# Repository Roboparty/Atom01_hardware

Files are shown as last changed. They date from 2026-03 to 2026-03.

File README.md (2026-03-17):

# ATOM01_HARDWARE - RoboParty Humanoid Robot Open Source Project

**[中文](./README_cn.md)** | English

> **Project Introduction:** This repository serves as the core open-source hardware library for the **ATOM01** series of humanoid robots. We are committed to lowering the barrier to entry for bipedal robot development by providing a complete solution encompassing mechanical design, PCB schematics, and firmware.

---

## 📂 Repository Overview (Structure)

The project is managed hierarchically based on **version iterations**, containing two primary development branches: **V1.0** and **V2.0**.

### 📊 V1.0 vs V2.0 Feature Comparison

| Feature | V1.0 (Legacy) | V2.0 (Current / Recommended) |
| :--- | :--- | :--- |
| **Mechanical Design** | Original Design | **Reinforced Structure** |
| **Hardware Architecture** | Discrete Modules | **Highly Integrated Single Board** |
| **Core Improvements** | - | **Waist Limiting, Pin Calibration, Backplate Switch** |
| **Use Case** | Legacy User Maintenance | New User Development, Mass Production |

---

### 🔧 V1.0 (atom01_mechanic / atom01_pcb)
**Positioning:** Original version containing the early mechanical structure and discrete circuit board design.

-   **Core Components:**
    -   **Mechanical:** Basic bipedal structure design, including early assembly documentation and URDF files.
    -   **Hardware:** Separate Power and Communication boards (Roboto_Power, Roboto_Usb2Can).
-   **Target Audience:** Limited to legacy users still utilizing the first-generation hardware for reference.

### 🚀 V2.0 (roboto_origin_mechanic / roboto_origin_pcb)
**Positioning:** Brand new optimized version, comprehensively restructured for usability, stability, and integration.

#### ✨ Core Update Highlights
-   **🚀 Hardware System: Single Board Integration**
    -   **Optimization:** Integrated modules such as power management and communication interfaces into a **single core circuit board**.
    -   **Advantage:** Significantly simplifies internal cabling, reduces connector failure points, and enhances system stability and EMC (Electromagnetic Compatibility).
-   **⚙️ Mechanical System: Structural Reinforcement & Calibration Upgrade**
    -   **Waist Limiting:** Added a **mechanical limit switch** to ensure absolute safety for waist rotation angles.
    -   **Calibration Method:** Introduced **limit pin calibration** process, replacing the generic calibration method of the old version.
    -   **Arm Optimization:** Corrected issues present in the arm components of the previous version.
    -   **Backplate Switch:** Added a physical **main control board switch** to the robot's backplate.
-   **Target Audience:** All new users, developers, and users looking to experience the latest features.

---

## 📚 Quick Start

Please enter the corresponding directory based on your hardware version to obtain detailed documentation:

.  **V2.0 Users (Recommended):**
    -   **Mechanical Drawings:** Enter `V2.0/roboto_origin_mechanic/` to view assembly drawings and STL files.
    -   **PCB Files:** Enter `V2.0/roboto_origin_pcb/` to obtain Gerber files and schematics.
.  **V1.0 Users:**
    -   **Mechanical Drawings:** Enter `V1.0/atom01_mechanic/`.
    -   **PCB Files:** Enter `V1.0/atom01_pcb/`.

---

> **Note:** The mechanical structure and hardware interfaces of **V2.0 are not compatible with V1.0**. Please confirm the version before assembly or purchasing materials.

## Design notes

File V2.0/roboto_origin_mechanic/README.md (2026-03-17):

# ROBOTO

**[中文](./README_cn.md)** | English

> **Project Introduction:** This project is an open-source bipedal robot. It aims to lower the assembly threshold by providing a "nanny-level" assembly tutorial from mechanical structure to circuit connection.

---

## 📚 Core Documentation Navigation

We have prepared detailed PDF manuals for beginners. **Please be sure to read them in the following order:**

| Order | Document Name | Description | Location |
| :---: | :--- | :--- | :--- |
| 1️⃣ | **[Installation Manual-0317.pdf](00_Docs/安装手册-0317.pdf)** | Core assembly tutorial | `00_Docs/` |
| 2️⃣ | **[Roboto_origin Wiring Guide.pdf](00_Docs/Roboto_origin走线说明.pdf)** | Electronic wiring guide | `00_Docs/` |
| 3️⃣ | **[Pin Calibration Guide.pdf](00_Docs/插销标定说明.pdf)** | Pin calibration method | `00_Docs/` |
| 4️⃣ | **[3D Printed Parts Calibration Guide.pptx](00_Docs/3D打印件标定说明.pptx)** | 3D printing calibration guide | `00_Docs/` |

---

## 📂 Project File Structure

This repository uses a modular structure, organized as follows:

```text
├── 00_Docs/                         # [Docs] Core manuals and lists
│   ├── 3D打印件标定说明.pptx        # 3D Printing Calibration Guide
│   ├── 安装手册-0317.pdf             # Installation Manual
│   ├── 插销标定说明.pdf              # Pin Calibration Guide
│   ├── Roboto头原型机 (RoboParty Roboto Origin) 散件清单 V1.1.3.xlsx # Parts List
│   ├── Original-0310.pdf             # Original Document
│   ├── Roboto_origin走线说明.pdf     # Wiring Guide
│
├── 01_SW_Project/                   # [Source] SolidWorks engineering files
│   └── robo_origin_2.0               # Roboto Origin 2.0 SW Project
│
├── 02_Manufacturing/                # [Manufacturing] Production files
│   ├── 3D_Printing                  # 3D Printing related files
│   └── CNC_Machining                # CNC Machining related files
│
└── 03_URDF/                         # [Simulation] Robot Description Files
    ├── meshes                       # Simulation model mesh files
    ├── urdf                         # URDF configuration files
    ├── Readme.md                    # URDF folder Readme
    └── robo_origin.png              # Image file

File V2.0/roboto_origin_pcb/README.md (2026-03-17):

# RBE_Board V2.0 - Robotic Electrical Hub

**[中文](./README_cn.md)** | English





> **Project Introduction:** The **RBE_Board V2.0** is an integrated circuit board designed by **RoboParty** for high-performance bipedal robots. It integrates three key functions: **48V-to-5V step-down conversion**, **power distribution**, and **USB-to-CAN communication**. This board acts as the "electrical hub" of the robot, responsible for power allocation and communication signal distribution.

---

## 📖 Specifications

As the key connection between the battery, the main control board (e.g., Orange Pi 5 Plus), and the limb actuators, the core specifications are as follows:

### 1. Hardware Specifications Table

| Parameter Category | Specification | Notes |
| :--- | :--- | :--- |
| **Power Input** | XT60 Terminal, 48VDC | Connect to Battery PACK |
| **5V Output** | Type-C Interface, Max 8A | Power supply for Main Control Board (e.g., Orange Pi 5 Plus) |
| **48V Output** | XT30 (2+2) Terminals × 4 | Distributed to limb motors |
| **Communication Interface** | USB 2.0 (Type-C) | Connects to Main Control Board for USB-to-CAN function |
| **Cooling Supply** | GH1.25 Interface, 5V | Powers system fans |
| **Dimensions** | 80mm × 60mm | Compact design |

---

## 📂 Repository Structure

This repository contains all engineering files required for manufacturing and utilizing this module:

```text
├── 00_Docs/                         # Documentation
│   ├── Images/                      # Interface & Render Images
│   │   ├── RBE_Board_v2.0_interface_bottom.PNG  # Bottom Interface Definition
│   │   ├── RBE_Board_v2.0_interface_top.PNG     # Top Interface Definition
│   │   └── RBE_Board_v2.0_render.JPEG           # 3D Render Image
│   ├── 3D_PCB5_11_2026-2-1.step    # 3D Structure Model File
│   └── 三合一电路V1.0硬件说明.pdf   # Detailed Hardware Design Principles (Chinese)
│
├── 01_Gerber/                       # PCB Manufacturing Files
│   └── Gerber_RBE_Board_v2.0.zip    # Gerber File Archive
│
├── 02_Assembly/                     # Assembly Files
│   ├── BOM_RBE_Board_v2.0.xlsx      # Bill of Materials (BOM)
│   └── PickAndPlace_RBE_Board_v2.0.xlsx # Pick and Place Coordinates
│
├── README.md                        # English Readme
└── README_cn.md                     # Chinese Readme

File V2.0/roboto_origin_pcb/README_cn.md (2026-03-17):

# RBE_Board V2.0 - 机器人电气核心枢纽

**[中文](./README_cn.md)** | [English](./README.md)

!<Manufacturer>
!<Hardware>
!<OS>

> **项目简介：** RBE_Board V2.0 是萝博派对 (RoboParty) 专为高性能双足机器人设计的集成化电路板。该板卡将 **48V转5V降压模块**、**分电板** 以及 **USB转CAN (USB2CAN)** 功能集成于一体，作为机器人的“电气中转站”，负责电源分配与通信信号分发。

---

## 📖 核心功能与规格 (Specifications)

本模块作为连接电池、主控板（如香橙派5Plus）与四肢执行器的关键枢纽，核心参数如下：

### 1. 硬件参数表

| 参数类别 | 具体规格 | 备注 |
| :--- | :--- | :--- |
| **供电输入** | XT60端子, 48VDC | 连接电池 PACK |
| **5V 输出** | Type-C接口, 最高持续电流 8A | 为主控板、供电 |
| **48V 输出** | XT30 (2+2) 端子 × 4 | 分配至机器人四肢电机 |
| **通信接口** | USB2.0 (Type-C) | 连接主控板，实现 USB 转 CAN 功能 |
| **散热供电** | GH1.25 接口, 5V | 为系统风扇供电 |
| **尺寸** | 80mm × 60mm | 紧凑型设计 |

---

## 📂 仓库目录结构 (File Structure)

本仓库包含制造和使用该模块所需的全部工程文件：

```text
├── 00_Docs/                         # 文档目录
│   ├── Images/                      # 接口与渲染图
│   │   ├── RBE_Board_v2.0_interface_bottom.PNG  # 底部接口定义
│   │   ├── RBE_Board_v2.0_interface_top.PNG     # 顶部接口定义
│   │   └── RBE_Board_v2.0_render.JPEG           # 3D渲染效果图
│   ├── 3D_PCB5_11_2026-2-1.step    # 3D结构模型文件
│   └── 三合一电路V1.0硬件说明.pdf   # 详细硬件设计原理
│
├── 01_Gerber/                       # PCB制造文件
│   └── Gerber_RBE_Board_v2.0.zip    # Gerber文件压缩包
│
├── 02_Assembly/                     # 装配文件
│   ├── BOM_RBE_Board_v2.0.xlsx      # 物料清单
│   └── PickAndPlace_RBE_Board_v2.0.xlsx # 贴片坐标文件

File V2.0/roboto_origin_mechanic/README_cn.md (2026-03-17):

# ROBOTO

**[中文](./README_cn.md)** | [English](./README.md)

> **项目简介：** 本项目是一个开源的双足机器人。本项目致力于降低组装门槛，提供了从机械结构到电路连接的“保姆级”装配教程。

---

## 📚 核心文档导航 (Documentation)

我们为初学者准备了详细的 PDF 手册，请**务必按照以下顺序阅读**：

| 顺序 | 文档名称 | 内容说明 | 存放位置 |
| :---: | :--- | :--- | :--- |
| 1️⃣ | **[安装手册-0317.pdf](00_Docs/安装手册-0317.pdf)** | 核心组装教程 | `00_Docs/` |
| 2️⃣ | **[Roboto_origin走线说明.pdf](00_Docs/Roboto_origin走线说明.pdf)** | 电子接线指导 | `00_Docs/` |
| 3️⃣ | **[插销标定说明.pdf](00_Docs/插销标定说明.pdf)** | 插销标定方法 | `00_Docs/` |
| 4️⃣ | **[3D打印件标定说明.pptx](00_Docs/3D打印件标定说明.pptx)** | 3D打印件标定说明 | `00_Docs/` |

---

## 📂 项目文件架构 (File Structure)

本仓库采用模块化结构，文件组织如下：

```text
├── 00_Docs/                         # [文档] 核心说明书
│   ├── 安装手册-0317.pdf            # 核心安装手册
│   ├── 插销标定说明.pdf             # 插销标定说明
│   ├── Roboto头原型机 (RoboParty Roboto Origin) 散件清单 V1.1.3.xlsx # 散件清单
│   ├── Original-0310.pdf            # 产品介绍书
│   ├── robo_origin SOP.pdf          # 标准作业程序
│   └──Roboto_origin走线说明.pdf      # 走线说明  
│
├── 01_SW_Project/                   # [源文件] solidworks工程文件
│   └── robo_origin_2.0              # Roboto Origin 2.0 工程文件
│
├── 02_Manufacturing/                # [制造] 生产加工文件
│   ├── 3D_Printing                  # 3D打印相关文件
│   └── CNC_Machining                # CNC加工相关文件
│
└── 03_URDF/                         # [仿真] 机器人描述文件
    ├── meshes                       # 仿真模型网格文件
    ├── urdf                         # URDF配置文件

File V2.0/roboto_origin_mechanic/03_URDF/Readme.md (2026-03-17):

This is the URDF file of Atom01, a product of Roboparty.
Atom01 URDF 模型  
  <link
    name="left_ankle_roll_link">
    <inertial>
      <origin
        xyz="0.01521399 0.00220247 -0.02960539"
        rpy="0 0 0" />
      <mass
        value="0.32034036 " />
      <inertia
        ixx=" 0.000402"
        ixy="0"
        ixz="0.00017084"
        iyy="0.00089244"
        iyz="-0.00000894"
        izz="0.0006553" />
    </inertial>

      <link
    name="right_ankle_roll_link">
    <inertial>
      <origin
        xyz="0.01521399 -0.00220269 -0.02960539"
        rpy="0 0 0" />
      <mass
        value="0.32034036" />
      <inertia
        ixx="0.000402"
        ixy="0"
        ixz="-0.00017084"
        iyy="0.00089244"
        iyz="-0.00000894"
        izz="0.0006553" />
    </inertial>

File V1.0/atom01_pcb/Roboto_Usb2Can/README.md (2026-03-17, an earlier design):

# Roboto_Usb2Can_V1.0 - USB to 4-Channel CAN Communication Module

[English](./README.md) | **[🇨🇳 中文](./README_cn.md)**





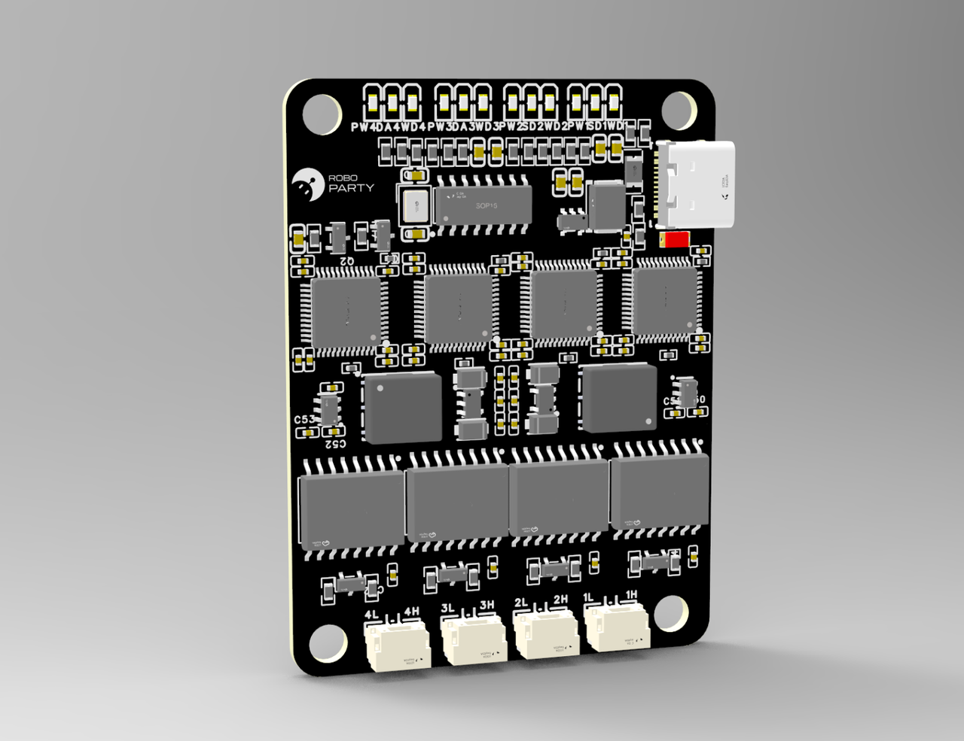
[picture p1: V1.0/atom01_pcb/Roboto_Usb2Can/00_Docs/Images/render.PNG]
Render


## 📖 Overview

**Roboto_Usb2Can_V1.0** is a highly integrated communication conversion device developed by **RoboParty**.

Designed primarily for robot control systems, this module converts USB signals from a host computer (such as an Orange Pi 5 Plus or other Linux devices) into **4 independent CAN bus signals**, enabling efficient control of actuators like servo motors.

> ⚠️ **Note:** This device currently only supports recognition and usage on **Linux systems**.

## 📂 Repository Structure

This repository contains all files required to manufacture and use this module:

- **PCB Manufacturing Files (Gerber):** `01_Gerber/`
- **BOM & Coordinate Files:** `02_Assembly/`
- **Firmware Files:** `03_Firmware/`
- **Detailed Documentation:** `00_Docs/`

## 🔌 Interfaces

### 1. Hardware Interface Layout
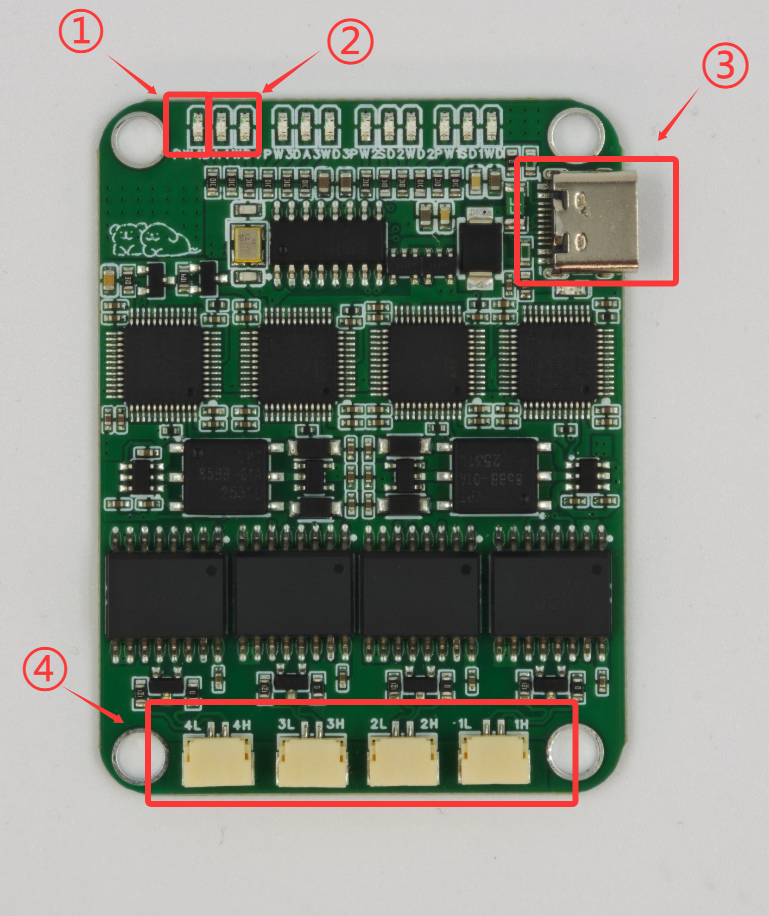
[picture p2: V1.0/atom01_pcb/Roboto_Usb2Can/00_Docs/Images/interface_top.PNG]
Interfaces


| No. | Name | Type | Description |
| :--- | :--- | :--- | :--- |
| **①/④** | **Mounting Holes** | Mechanical | Standard mounting holes |
| **②** | **Flashing LEDs** | LED | Status indicators for the 4 backend channels |
| **③** | **USB-C** | Data/Power | Connects to Host (Linux), 5V Input |
| **④** | **CAN Interfaces** | GH1.25 | 4-channel CAN bus output (4L, 4H, 3L, 3H...) |

### 2. Recommended Connection Topology
For easier management, we recommend connecting the robot joints in the following order:

- **CAN 1:** Left Leg 
- **CAN 2:** Right Leg(including Waist)
- **CAN 3:** Left Arm
- **CAN 4:** Right Arm

## 🛠️ Firmware Flashing Guide

There are 4 sets of SWD programming interfaces reserved on the back of the device. You will need to use **1.25mm programming probes (pogo pins)** with an ST-Link or similar tool.

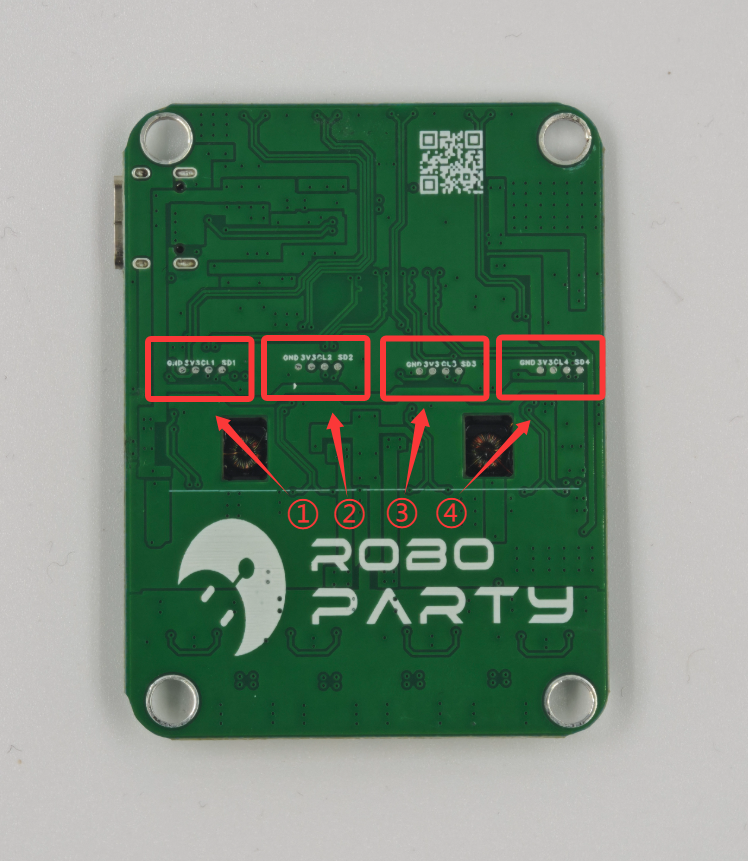
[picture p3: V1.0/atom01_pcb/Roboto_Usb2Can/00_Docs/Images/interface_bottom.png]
Flashing Ports


### Flashing Steps:
1.  **Download Firmware:** Get [RoboParty-HubUsb2Can_1.00.bin](03_Firmware/RoboParty-HubUsb2Can_1.00.bin).
2.  **Connect Programmer:** The pinout from left to right is: `GND`, `3V3`, `CLK`, `DIO`.
3.  **Sequential Flashing:** Please flash the firmware to the **4 programming ports** on the back one by one (each port corresponds to one CAN control chip).

## ⚠️ Precautions

1.  **Power Safety:**
    * **5V Power Supply ONLY.** Do not connect higher voltages.
    * Do not forcibly insert the Type-C cable in reverse.
2.  **Termination Resistors:**
    * The CAN bus specification requires a **120Ω termination resistor** at the end of each bus.
    * If your servo motors have internal resistors, no extra action is needed; otherwise, you must add a parallel resistor at the end of the chain.
3.  **Environmental Requirements:**
    * Avoid contact with water, conductive dust, or metal debris to prevent short circuits.

## 🏭 Manufacturing Downloads

If you need to manufacture this module yourself, please download the following files:

* **Gerber Files (PCB Fab):** [Roboto_Usb2Can_V1.0.rar](01_Gerber/Roboto_Usb2Can_V1.0.rar)
* **Bill of Materials (BOM):** [HUB-USB2CAN_Bom.xlsx](02_Assembly/HUB-USB2CAN_Bom.xlsx)
* **Pick & Place Coordinates (CPL):** [PickAndPlace.xlsx](02_Assembly/PickAndPlace_HUB_USBTOCAN_V1_0.xlsx)

---
**Tech Support:** If you encounter technical issues, please contact the RoboParty technical team.

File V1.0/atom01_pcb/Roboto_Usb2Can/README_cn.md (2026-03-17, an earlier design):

# Roboto_Usb2Can_V1.0 - USB 转 4路 CAN 通讯模块

**[中文](./README_cn.md)** | [English](./README.md)





Render

## 📖 概述 (Overview)

**Roboto_Usb2Can_V1.0** 是由 **萝博派对 (RoboParty)** 研发的高集成度通讯转换设备。

该模块主要用于机器人控制系统，能够将上位机（如 Orange Pi 5 Plus 等 Linux 设备）的 USB 信号转换为 **4 路独立的 CAN 总线信号**，从而实现对伺服电机等执行机构的高效控制。

> ⚠️ **注意：** 本设备目前仅支持在 **Linux 系统** 下识别和使用。

## 📂 仓库目录 (File Structure)

本仓库包含制造和使用该模块所需的所有文件：

- **PCB 制造文件 (Gerber):** `01_Gerber/`
- **BOM 与坐标文件:** `02_Assembly/`
- **固件文件:** `03_Firmware/`
- **详细说明文档:** `00_Docs/`

## 🔌 接口定义 (Interfaces)

### 1. 硬件接口布局
Interfaces

| 编号 | 名称 | 类型 | 说明 |
| :--- | :--- | :--- | :--- |
| **①/④** | **固定孔** | 机械 | 标准安装孔位 |
| **②** | **烧录指示灯** | LED | 对应背部 4 路烧录状态 |
| **③** | **USB-C** | 数据/电源 | 连接上位机 (Linux)，输入电压 5V |
| **④** | **CAN 接口** | GH1.25 | 4路 CAN 总线输出 (4L, 4H, 3L, 3H...) |

### 2. 执行机构连接推荐
为方便管理，建议按照以下对应关系连接机器人关节：

- **CAN 1:** 左腿 
- **CAN 2:** 右腿(含腰关节)
- **CAN 3:** 左臂
- **CAN 4:** 右臂

## 🛠️ 烧录指南 (Firmware Flashing)

本设备背面预留了 4 组 SWD 烧录接口，需要使用 **1.25mm 烧录针** 配合 ST-Link 或类似工具进行烧录。

Flashing Ports

### 烧录步骤：
1. **固件下载：** 获取 [RoboParty-HubUsb2Can_1.00.bin](03_Firmware/RoboParty-HubUsb2Can_1.00.bin)。
2. **连接烧录器：** 接口定义从左至右依次为：`GND`, `3V3`, `CLK`, `DIO`。
3. **顺序烧录：** 请依次对背面的 **4 个烧录口** 进行固件烧录（每个接口对应一路 CAN 控制芯片）。

## ⚠️ 注意事项 (Precautions)

1.  **电源安全：**
    * 仅限 **5V** 供电，严禁接入更高电压。
    * 请勿反向暴力插拔 Type-C 线缆。
2.  **终端电阻：**
    * CAN 总线规范要求每路总线末端需接 **120Ω 终端电阻**。
    * 如果您的伺服电机内部已集成电阻，则无需额外添加；否则必须在末端并联电阻。
3.  **环境要求：**
    * 避免接触水、导电灰尘或金属碎屑，防止短路。

## 🏭 制造文件下载 (Downloads)

如果您需要自行制造该模块，请下载以下文件：

* **Gerber 文件 (打板):** [Roboto_Usb2Can_V1.0.rar](01_Gerber/Roboto_Usb2Can_V1.0.rar)
* **物料清单 (BOM):** [HUB-USB2CAN_Bom.xlsx](02_Assembly/HUB-USB2CAN_Bom.xlsx)
* **贴片坐标 (CPL):** [PickAndPlace.xlsx](02_Assembly/PickAndPlace_HUB_USBTOCAN_V1_0.xlsx)

---
**技术支持:** 如遇到技术问题，请联系 RoboParty 技术团队。

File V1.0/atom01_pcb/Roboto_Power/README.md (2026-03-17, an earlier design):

# Roboto_Power_V1.0 - Robot Core Power Distribution Board

[English](./README.md) | **[🇨🇳 中文](./README_cn.md)**





Render

## 📖 Overview

**Roboto_Power_v1.0** is the core component of the Roboto prototype's electrical system.

Acting as the robot's energy hub, it is responsible for distributing the main battery power to various motors and control modules, implementing a "centralized control & distributed power" architecture. This power distribution board (PDB) works in conjunction with the following modules to form the complete electrical system:
* Host Computer (Orange Pi 5 Plus)
* 48V to 5V Buck Converter Module
* USB-to-CAN Communication Board

## 📂 Repository Structure

This repository contains all files required to manufacture this power board:

- **PCB Manufacturing Files (Gerber):** `01_Gerber/`
- **BOM & Coordinate Files:** `02_Assembly/`
- **Detailed Documentation:** `00_Docs/`

## 🔌 Interface Definitions

### 1. Top Layer Layout
Interfaces Top

| No. | Interface Type | Description | Notes |
| :--- | :--- | :--- | :--- |
| **①** | **Main Power Input** | XT60/XT90 (Male) | Connects to the main battery |
| **②** | **Power Split Output** | XT30 (Female) | Power supply for joint motors (6 channels) |
| **③** | **CAN Signal Hub** | GH1.25 | 4-channel CAN bus signal distribution (Top) |

### 2. Bottom Layer Layout
Interfaces Bottom

| No. | Interface Type | Description |
| :--- | :--- | :--- |
| **④** | **CAN Signal Extension** | GH1.25 Connector, used for extending more CAN nodes or connecting the USB-to-CAN module |

> **Note:** This board integrates a CAN bus hub function to simplify wiring layouts.

## ⚠️ Critical Precautions

> 🛑 **Please read carefully before operation! Incorrect operation will result in equipment damage!**

1.  **Power Polarity:**
    * **PAY ATTENTION TO POSITIVE AND NEGATIVE POLARITY!!**
    * **PAY ATTENTION TO POSITIVE AND NEGATIVE POLARITY!!**
    * **PAY ATTENTION TO POSITIVE AND NEGATIVE POLARITY!!**
    * Before connecting the battery, be sure to use a multimeter to check for short circuits at the input terminals.

2.  **CAN Wiring Sequence:**
    * Strictly check the silkscreen markings `H` (High) and `L` (Low) on the board.
    * Connect CAN_H to CAN_H, and CAN_L to CAN_L. **Do not reverse them**, otherwise communication will fail.

## 🏭 Manufacturing Downloads

If you need to manufacture this module yourself, please download the following files:

* **Gerber Files (PCB Fab):** [POWER_BOARD_GERBER_V1.0.zip](01_Gerber/POWER_BOARD_GERBER_V1.0.zip)
* **Bill of Materials (BOM):** [BOM_POWER_BOARD-V1.0.xlsx](02_Assembly/BOM_POWER_BOARD-V1.0.xlsx)
* **Pick & Place Coordinates (CPL):** [PickAndPlace_POWER_BOARD_V1_0.xlsx](02_Assembly/PickAndPlace_POWER_BOARD_V1_0.xlsx)

---
**Tech Support:** If you encounter technical issues, please contact the RoboParty technical team.

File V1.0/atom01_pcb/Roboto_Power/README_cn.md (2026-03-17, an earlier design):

# Roboto_Power_V1.0 - 机器人核心分电板

**[中文](./README_cn.md)** | [English](./README.md)





Render

## 📖 概述 (Overview)

**Roboto_Power_v1.0** 是 Roboto 原型机电气系统的核心组件。

作为机器人的能量枢纽，它负责将电池输入的总电源分配至各个电机及控制模块，实现了“集中控制与分布式供电”的架构。该分电板与以下模块共同构成了完整的电气系统：
* 上位机 (Orange Pi 5 Plus)
* 48V 转 5V 降压模块
* USB-to-CAN 通讯板

## 📂 仓库目录 (File Structure)

本仓库包含制造该分电板所需的所有文件：

- **PCB 制造文件 (Gerber):** `01_Gerber/`
- **BOM 与坐标文件:** `02_Assembly/`
- **详细说明文档:** `00_Docs/`

## 🔌 接口定义 (Interfaces)

### 1. 正面接口布局
Interfaces Top

| 编号 | 接口类型 | 说明 | 备注 |
| :--- | :--- | :--- | :--- |
| **①** | **电源输入 (Main In)** | XT60/XT90 (公) | 连接电池主电源 |
| **②** | **电源分流输出** | XT30 (母) | 分配给各个关节电机供电 (6路) |
| **③** | **CAN 信号集线器** | GH1.25 | 4路 CAN 总线信号分发 (正面) |

### 2. 背面接口布局
Interfaces Bottom

| 编号 | 接口类型 | 说明 |
| :--- | :--- | :--- |
| **④** | **CAN 信号扩展** | GH1.25 连接器，用于扩展更多 CAN 节点或连接 USB转CAN 模块 |

> **提示：** 本板集成了 CAN 总线集线器功能，方便走线布局。

## ⚠️ 极重要注意事项 (Critical Precautions)

> 🛑 **请在操作前仔细阅读！错误操作将导致设备烧毁！**

1.  **电源极性 (Polarity):**
    * **接线一定注意正负极！！**
    * **接线一定注意正负极！！**
    * **接线一定注意正负极！！**
    * 插上电池前，请务必使用万用表检查输入端正负极是否短路。

2.  **CAN 线序:**
    * 请严格核对板上丝印 `H` (High) 和 `L` (Low)。
    * CAN_H 接 CAN_H，CAN_L 接 CAN_L，**切勿接反**，否则会导致通讯中断。

## 🏭 制造文件下载 (Downloads)

如果您需要自行制造该模块，请下载以下文件：

* **Gerber 文件 (打板):** [POWER_BOARD_GERBER_V1.0.zip](01_Gerber/POWER_BOARD_GERBER_V1.0.zip)
* **物料清单 (BOM):** [BOM_POWER_BOARD-V1.0.xlsx](02_Assembly/BOM_POWER_BOARD-V1.0.xlsx)
* **贴片坐标 (CPL):** [PickAndPlace_POWER_BOARD_V1_0.xlsx](02_Assembly/PickAndPlace_POWER_BOARD_V1_0.xlsx)

---
**技术支持:** 如遇到技术问题，请联系 RoboParty 技术团队。

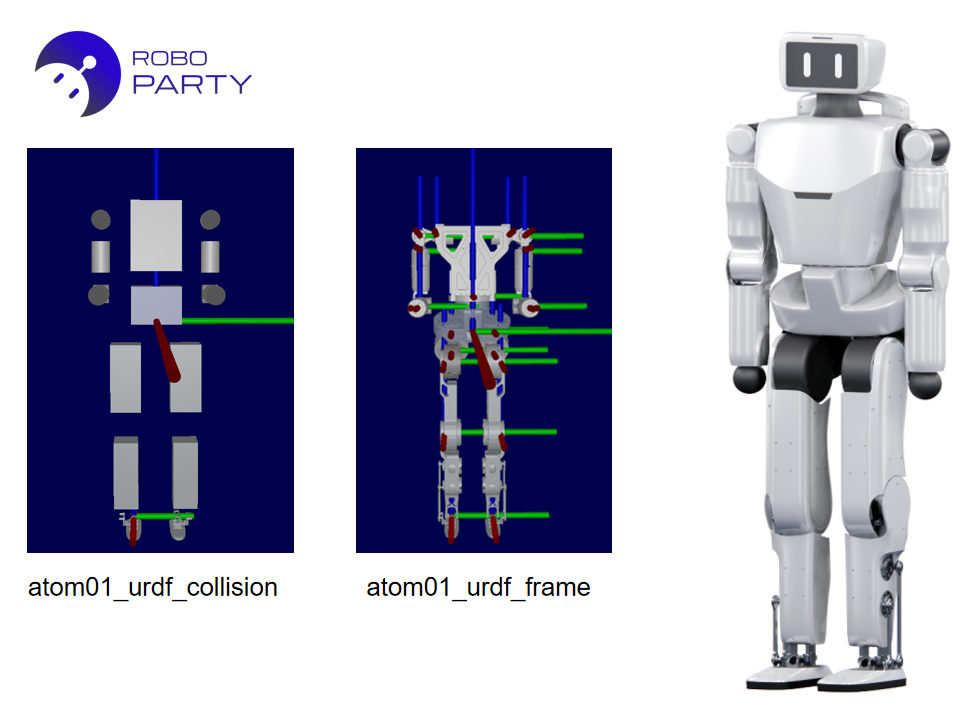
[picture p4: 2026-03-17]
V2.0/roboto_origin_mechanic/03_URDF/roboto_origin.png

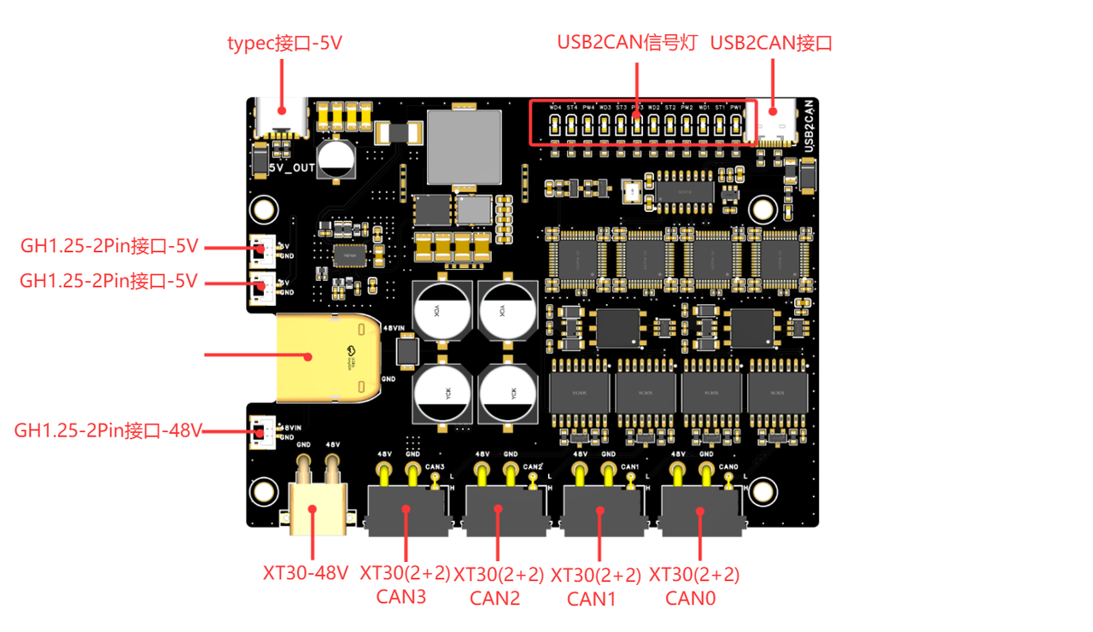
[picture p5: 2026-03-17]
V2.0/roboto_origin_pcb/00_Docs/Images/RBE_Board_v2.0_interface_top.PNG

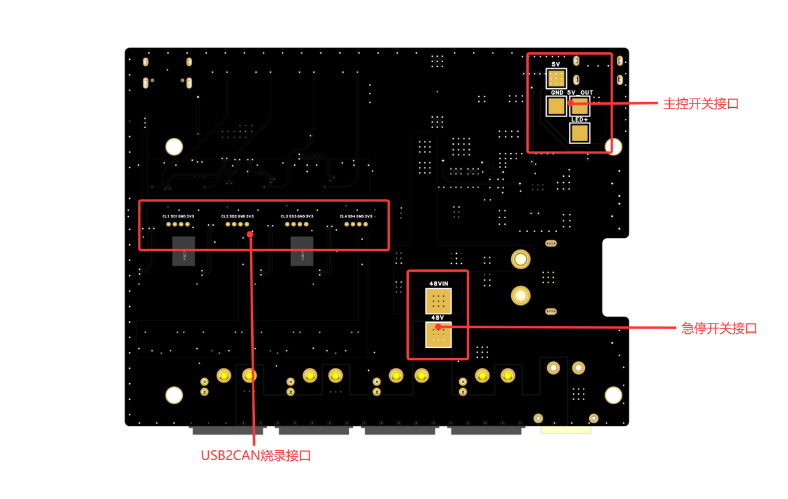
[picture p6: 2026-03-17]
V2.0/roboto_origin_pcb/00_Docs/Images/RBE_Board_v2.0_interface_bottom.PNG

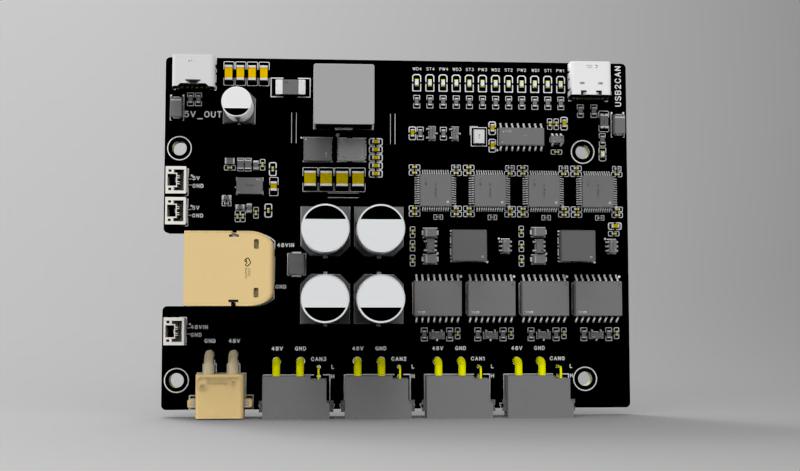
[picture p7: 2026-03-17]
V2.0/roboto_origin_pcb/00_Docs/Images/RBE_Board_v2.0_render.JPEG

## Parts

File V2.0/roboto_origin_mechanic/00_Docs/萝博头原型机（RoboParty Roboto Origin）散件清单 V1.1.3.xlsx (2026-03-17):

 |  |  | Open source BOM for Roboto
Total Price: |  | Edit by： | @Qihang Cai
Version： | v1.1.3 | Review by： | @haonan sun
Product Model: | Roboto | Approval by： | @Baoxin Zhang
版本说明：v1.1.3 将天线的材质从1pex一代改为15cm线长，ipex一代
Number | Part Name | name | Quantity/material | Unit | Version | Classification | 保修
RB-roboto-01 | 结构件 | 手臂1 | 6061铝合金 | 2 | pcs | 120目喷砂/黑色阳极氧化 | 嘉立创保修 | A | 大礼包
RB-roboto-02 |  | 手臂2 | 6061铝合金 | 4 | pcs | 120目喷砂/黑色阳极氧化
RB-roboto-03 |  | 手臂3 | 6061铝合金 | 4 | pcs | 120目喷砂/黑色阳极氧化
RB-roboto-04 |  | 手臂4 | 6061铝合金 | 4 | pcs | 120目喷砂/黑色阳极氧化
RB-roboto-05 |  | IMU载板 | 6061铝合金 | 1 | pcs | 120目喷砂/黑色阳极氧化
RB-roboto-06 |  | 侧板横板 | 6061铝合金 | 2 | pcs | 120目喷砂/黑色阳极氧化
RB-roboto-07 |  | 大腿内侧 | 6061铝合金 | 2 | pcs | 120目喷砂/黑色阳极氧化
RB-roboto-08 |  | 电池底盖 | 7075铝合金 | 1 | pcs | 120目喷砂/黑色阳极氧化
RB-roboto-09 |  | 肩膀 | 6061铝合金 | 2 | pcs | 120目喷砂/黑色阳极氧化
RB-roboto-10 |  | 20cm脚 | 6061铝合金 | 2 | pcs | 120目喷砂/黑色阳极氧化
RB-roboto-11 |  | 脚底连杆 | 45钢 | 2 | pcs | 发黑
RB-roboto-12 |  | 脚踝横滚连接件 | 6061铝合金 | 4 | pcs | 120目喷砂/黑色阳极氧化
RB-roboto-13 |  | 髋关节固定 | 6061铝合金 | 1 | pcs | 120目喷砂/黑色阳极氧化
RB-roboto-14 |  | 输出法兰连杆 | 45钢 | 4 | pcs | 发黑
RB-roboto-15 |  | 通用连接件 | 6061铝合金 | 4 | pcs | 120目喷砂/黑色阳极氧化
RB-roboto-16 |  | 通用连接件扩孔法兰 | 6061铝合金 | 4 | pcs | 120目喷砂/黑色阳极氧化
RB-roboto-17 |  | 小腿 | 6061铝合金 | 2 | pcs | 120目喷砂/黑色阳极氧化
RB-roboto-18 |  | 胸腔夹板后 | 6061铝合金 | 1 | pcs | 120目喷砂/黑色阳极氧化
RB-roboto-19 |  | 胸腔夹板前 | 6061铝合金 | 1 | pcs | 120目喷砂/黑色阳极氧化
RB-roboto-20 |  | 限位销 | 6061铝合金 | 4 | pcs | 120目喷砂/黑色阳极氧化
RB-roboto-21 |  | 小腿轴承锁 | 6061铝合金 | 4 | pcs | 120目喷砂/黑色阳极氧化
RB-roboto-22 |  | 腰部支撑 | 7075铝合金 | 1 | pcs | 120目喷砂/黑色阳极氧化
RB-roboto-23 |  | 长连杆 | 45钢 | 2 | pcs | 发黑
RB-roboto-24 |  | 短连杆 | 45钢 | 2 | pcs | 发黑
RB-roboto-25 |  | 髋夹板 | 6061铝合金 | 2 | pcs | 120目喷砂/黑色阳极氧化
RB-roboto-26 |  | 手臂5 | 6061铝合金 | 2 | pcs | 120目喷砂/黑色阳极氧化
RB-roboto-27 |  | 橡胶脚底 | 橡胶 | 2 | pcs
RB-roboto-28 | 电池组件 | 48V 15Ah锂电池 | 140*140*115mm 孚小二 | 1 | pcs | - | 孚小二保修 | B
RB-roboto-29 |  | 锂电池充电器 | 3pin航空插头 | 1 | pcs | -
RB-roboto-30 | 执行器 | DM 4340P（48V） |  | 14 |  | - | 达妙保修
RB-roboto-31 |  | DM 10010L （48V） |  | 9 |  | -
RB-roboto-32 |  | DMFDCAN分析仪 |  | 1
RB-roboto-33 | 3D打印件 | ROBOTO Origin标定件 | 3d打印/躺倒标定/手臂垂直 | 8 | pcs | 自主打印 | 无 | \ | 小礼包
RB-roboto-34 |  | 载板固定件v2.0 | 3d打印 | 1 |  | 自主打印
RB-roboto-35 | IMU | 超核HI14M0-USB IMU/VRU USB-232 | 超核 | 1 | pcs | - | 超核提供保修 | B
RB-roboto-36 | 电子元器件 | RDK X5 8G | 8G/单板 | 1 | pcs | - | 地瓜保修
RB-roboto-37 |  | RTC | - | 1 | pcs | - | RP保修 | C
RB-roboto-38 |  | sd卡 | SanDisk 32g高速卡 | 1 | pcs | -
RB-roboto-39 |  | 天线 | 15cm线长，ipex一代 | 1
RB-roboto-40 |  | 散热套装 |  | 1
RB-roboto-41 |  | RBE_Board_v2.0 | 自制PCB板三合一 | 1 | pcs | -
RB-roboto-42 |  | 急停按钮 | 蓝波M3氧化头部-无灯 | 1 | pcs | -
RB-roboto-43 |  | 金属按钮开关 | 5V 绿灯 环形电源 带线插件 自锁 | 1 | pcs | -
RB-roboto-44 |  | 数字电压表 |  | 1
RB-roboto-45 |  | 手柄 | 手柄 | 1 | pcs | -
RB-roboto-46 |  | 束线固定座 |  | 1
RB-roboto-47 |  | 金属把手 |  | 1
RB-roboto-48 | 轴承 | 深沟球轴承130*165*18 | GB/T 276-2013 | 1 | pcs | - | RP保修
RB-roboto-49 |  | 向心关节轴承（G系列）8 | GB/T 9161-2001 | 8 | pcs | -
RB-roboto-50 |  | 推力滚针和保持架组件AXK6085 | GB/T 4605-2003 | 9 | pcs | -
RB-roboto-51 |  | 万向节十字轴承16×40 | JIS G 4805 | 2 | pcs | -
RB-roboto-52 | 线材 | RBW_Origin_01 Arm01 | XT30(+2)-F.G.B-XT30(+2)-F.G.B | 2 |  | 20cm | RP保修
RB-roboto-53 |  | RBW_Origin_02 Arm02 | XT30(+2)-F.G.B-XT30(+2) -F.G.B | 2 |  | 20cm
RB-roboto-54 |  | RBW_Origin_03 Arm03 | XT30(+2)-F.G.B-XT30(+2)-F.G.B | 2 |  | 20cm
RB-roboto-55 |  | RBW_Origin_04 Arm04 | XT30(+2)-F.G.B-XT30(+2)-F.G.B | 2 |  | 20cm
RB-roboto-56 |  | RBW_Origin_05 Leg01 | XT30U-F-XT30U-F (gh1.25 2pin 反线 35cm) | 2 |  | 25cm
RB-roboto-57 |  | RBW_Origin_06 Leg02 | XT30U-F-XT30U-F (gh1.25 2pin 反线 35cm) | 2 |  | 25cm
RB-roboto-58 |  | RBW_Origin_07 Leg03 | XT30U-F-XT30U-F (gh1.25 2pin 反线 30cm ) | 2 |  | 40cm
RB-roboto-59 |  | RBW_Origin_08 Leg04 | XT30U-F-XT30(+2)-F.G.B (gh1.25 2pin 反线 35cm) | 2 |  | 30cm
RB-roboto-60 |  | RBW_Origin_09 Leg05 | XT30(+2)-F.G.B-XT30(+2)-F.G.B 10cm | 2 |  | 10cm
RB-roboto-61 |  | RBW_Origin_10 Body01 | XT30U-F-XT30U-F (gh1.25 2pin 反线 30cm) | 1 |  | 20cm
RB-roboto-62 |  | RBW_Origin_11 Body02 | XT30(+2)-F.G.B-XT30(+2)-F.G.B | 2 |  | 20cm
RB-roboto-63 |  | RBW_Origin_12 Body03 | XT30(+2)-F.G.B - XT30U-F (gh1.25 2pin 反线 65cm) | 1 |  | 60cm
RB-roboto-64 |  | RBW_Origin_13 Body04 | XT30(+2)-F.G.B - XT30U-F (gh1.25 2pin 反线 55cm) | 1 |  | 50cm
RB-roboto-65 |  | usb to typec 3.0 30cm | 30cm | 1 | pcs
RB-roboto-66 |  | type- type c,软线，快充, 侧弯 | 30cm | 1 | pcs
RB-roboto-67 |  | RDK上调试线材
RB-roboto-68 | 紧固件 | 内六角圆柱头螺钉M2.5×8 | 12.9级合金钢 | 20 | pcs | GB/T 70.1-2000 | RP保修
RB-roboto-69 |  | 内六角圆柱头螺钉M3×6 | 12.9级合金钢 | 20 | pcs | GB/T 70.1-2000
RB-roboto-70 |  | 内六角圆柱头螺钉M3×8 | 12.9级合金钢 | 80 | pcs | GB/T 70.1-2000
RB-roboto-71 |  | 内六角圆柱头螺钉M3×10 | 12.9级合金钢 | 80 | pcs | GB/T 70.1-2000
RB-roboto-72 |  | 内六角圆柱头螺钉M3×12 | 12.9级合金钢 | 50 | pcs | GB/T 70.1-2000
RB-roboto-73 |  | 内六角圆柱头螺钉M3×16 | 12.9级合金钢 | 80 | pcs | GB/T 70.1-2000
RB-roboto-74 |  | 内六角圆柱头螺钉M4×8 | 12.9级合金钢 | 200 | pcs | GB/T 70.1-2000
RB-roboto-75 |  | 内六角圆柱头螺钉M4×10 | 12.9级合金钢 | 100 | pcs | GB/T 70.1-2000
RB-roboto-76 |  | 内六角圆柱头螺钉M4×12 | 12.9级合金钢 | 100 | pcs | GB/T 70.1-2000
RB-roboto-77 |  | 内六角圆柱头螺钉M4×14 | 12.9级合金钢 | 20 | pcs | GB/T 70.1-2000
RB-roboto-78 |  | 内六角圆柱头螺钉M5×10 | 12.9级合金钢 | 80 | pcs | GB/T 70.1-2000
RB-roboto-79 |  | 内六角圆柱头螺钉M5×12 | 12.9级合金钢 | 100 | pcs | GB/T 70.1-2000
RB-roboto-80 |  | 内六角圆柱头螺钉M5×14 | 12.9级合金钢 | 100 | pcs | GB/T 70.1-2000
RB-roboto-81 |  | 内六角圆柱头螺钉M6×16 | 12.9级合金钢 | 2 | pcs | GB/T 70.1-2001
RB-roboto-82 |  | 圆柱销4x18 | 45钢 | 30 | pcs | GB/T119.2-2000
RB-roboto-83 |  | 圆柱销4x22 | 45钢 | 30 | pcs | GB/T119.2-2000
RB-roboto-84 |  | 内六角圆柱头螺钉M6×12 | 12.9级合金钢 | 2 | pcs | GB/T 70.1-2000
RB-roboto-85 |  | 平头螺丝M4×12 | 12.9级合金钢 | 20 | pcs | 紧固件
RB-roboto-86 |  | 平头螺丝M5×16 | 12.9级合金钢 | 20 | pcs | 紧固件
RB-roboto-87 |  | 平头螺丝M4×8 | 12.9级合金钢 | 20 | pcs | 紧固件
RB-roboto-88 |  | 铜柱M3*15+3 | 12.9级合金钢 | 10 | pcs | 紧固件
RB-roboto-89 |  | 吊环螺钉M4 | 12.9级合金钢 | 4 | pcs | GB/T 825-1988

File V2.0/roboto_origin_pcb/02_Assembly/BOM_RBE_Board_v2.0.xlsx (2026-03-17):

No. | Quantity | Comment | Designator | Footprint | Value | Manufacturer Part | Manufacturer | Supplier Part | Supplier
1 | 4 | 100uF | C1,C21,C65,C66 | CAP-SMD_BD10.0-L10.3-W10.3-LS11.0-FD | 100uF | JVJ80V100M10x10 | JIERR(捷而瑞) | C46550424 | LCSC
2 | 40 | 100nF | C2,C3,C4,C5,C6,C7,C8,C11,C12,C13,C14,C15,C16,C17,C18,C19,C20,C24,C69,C103,C104,C105,C106,C107,C108,C109,C110,C111,C112,C113,C114,C115,C116,C117,C118,C119,C120,C121,C126,C127 | C0402 | 100nF | CL05B104KB54PNC | SAMSUNG(三星) | C307331 | LCSC
3 | 2 | 1uF | C9,C10 | C0402 | 1uF | CL05A105KA5NQNC | SAMSUNG(三星) | C52923 | LCSC
4 | 2 | 10uF | C22,C23 | C0402 | 10uF | CL05A106MQ5NUNC | SAMSUNG(三星) | C15525 | LCSC
5 | 1 | 1uF | C25 | C0603 | 1uF | CL10A105KB8NNNC | SAMSUNG(三星) | C15849 | LCSC
6 | 4 | 4.7uF | C49,C50,C51,C52 | C1210 | 4.7uF | FS32X475K101EGG | PSA(信昌电陶) | C381466 | LCSC
7 | 1 | 4.7nF | C54 | C0402 | 4.7nF | CC0402KRX7R9BB153 | YAGEO(国巨) |  | LCSC
8 | 4 | 47uF | C56,C57,C58,C74 | C1206 | 47uF | HGC1206R5476M160NSPJ | Chinocera(华瓷) | C7472975 | LCSC
9 | 1 | 330uF | C59 | CAP-SMD_BD6.3-L6.6-W6.6-LS7.4-FD | 330uF | JVJ10V330M6X8 | JIERR(捷而瑞) | C49256843 | LCSC
10 | 1 | 470nF | C60 | C0805 | 470nF | GRM21BR72A474KA73L | muRata(村田) | C97926 | LCSC
11 | 1 | 100nF | C61 | C0402 | 100nF | CL05B104KO5NNNC | SAMSUNG(三星) | C1525 | LCSC
12 | 1 | 2.2uF | C62 | C0603 | 2.2uF | CL05A475MP5NRNC | SAMSUNG(三星) |  | LCSC
13 | 1 | 0.1uF | C63 | C0402 | 0.1uF | HGC0402R5105K250NTEJ | Chinocera(华瓷) |  | LCSC
14 | 1 | 120pF | C64 | C0402 | 120pF | CC0402KRX7R9BB153 | YAGEO(国巨) |  | LCSC
15 | 5 | 10nF | C67,C68,C70,C71,C72 | C0603 | 10nF | CL10B103KC8NNNC | SAMSUNG(三星) | C84709 | LCSC
16 | 1 | 33pF | C73 | C0402 | 33pF | FCC0402N330J500AT | FOJAN(富捷) |  | LCSC
17 | 2 | 12pF | C122,C123 | C0603 | 12pF | CC0603JRNPO9BN120 | YAGEO(国巨) | C107034 | LCSC
18 | 1 | 22uF | C124 | C0603 | 22uF | CGA0603X5R226M160JT | HRE(芯声) | C6119868 | LCSC
19 | 2 | 100nF | C131,C132 | C0603 | 100nF | 06035C104JAT2A | Kyocera AVX | C129176 | LCSC
20 | 3 | WAFER-GH1.25-2PLB | CN1,CN4,CN5 | CONN-TH_2P-P1.25_XUNPU_WAFER-GH1.25-2PLB |  | WAFER-GH1.25-2PLB | XUNPU(讯普) | C3029368 | LCSC
21 | 1 | XT60PW-M | CN2 | CONN-TH_XT60PW-M |  | XT60PW-M | AMASS(艾迈斯) | C98732 | LCSC
22 | 1 | XT30PW-M30.G.Y | CN3 | CONN-TH_XT30PW-M |  | XT30PW-M30.G.Y | AMASS(艾迈斯) | C431092 | LCSC
23 | 4 | 0Ω | CS5,CS6,CS7,CS8 | R0603 | 0Ω | 0603WAF0000T5E | UNI-ROYAL(厚声) | C21189 | LCSC
24 | 2 | SMAJ6.0A | D1,D2 | SMA_L4.3-W2.6-LS5.2-RD |  | SMAJ6.0A | Littelfuse(美国力特) | C223993 | LCSC
25 | 4 | ESDA6V1L | D7,D8,D9,D10 | SOT-23-3_L2.9-W1.3-P1.90-LS2.4-BR |  | ESDA6V1L | TECH PUBLIC(台舟) | C587141 | LCSC
26 | 1 | FSMD100-1206R | F1 | F1206 |  | FSMD100-1206R | FUZETEC(富致) | C220149 | LCSC
27 | 1 | 6.8uH | L2 | IND-SMD_L12.8-W12.8-LS13.8_CYA1265 | 6.8uH | CYA1265-6.8UH | SHOU HAN(首韩) | C19268667 | LCSC
28 | 8 | SZYY0603B | LED14,LED16,LED17,LED19,LED20,LED22,LED23,LED25 | LED0603-R-RD_BLUE |  | SZYY0603B | yongyu(永裕光电) | C434421 | LCSC
29 | 4 | SZYY0603G | LED15,LED18,LED21,LED24 | LED0603-R-RD_GREEN |  | SZYY0603G | yongyu(永裕光电) | C434420 | LCSC
30 | 1 | NCD0603Y2 | LED26 | LED0603-RD |  | NCD0603Y2 | 国星光电 | C89811 | LCSC
31 | 1 | SI2301 | Q1 | SOT-23-3_L2.9-W1.3-P1.90-LS2.4-BR |  | SI2301 | YONGYUTAI(永裕泰) | C2891731 | LCSC
32 | 1 | SS8050 | Q2 | SOT-23-3_L2.9-W1.3-P1.90-LS2.4-BR |  | SS8050 | JSMSEMI(杰盛微) | C916392 | LCSC
33 | 1 | BSC028N06NS | Q5 | PG-TDSON-8_L5.0-W6.0-P1.27-LS6.2-BL-EP |  | BSC028N06NS | Infineon(英飞凌) | C148250 | LCSC
34 | 1 | NVMFS6H836NLT1G | Q6 | DFN-5_L4.9-W5.9-P1.27-LS6.2-BL |  | NVMFS6H836NLT1G | onsemi(安森美) | C900474 | LCSC
35 | 2 | 10K | R1,R2 | R0603 | 10K
36 | 8 | 10kΩ | R3,R4,R10,R11,R58,R59,R64,R65 | R0402 | 10kΩ | 0402WGF1002TCE | UNI-ROYAL(厚声) | C25744 | LCSC
37 | 4 | 120Ω | R5,R12,R60,R66 | R0603 | 120Ω | 0603WAF1200T5E | UNI-ROYAL(厚声) | C22787 | LCSC
38 | 12 | 1kΩ | R7,R8,R9,R13,R14,R15,R61,R62,R63,R67,R68,R69 | R0603 | 1kΩ | 0603WAF1001T5E | UNI-ROYAL(厚声) | C21190 | LCSC
39 | 1 | 41.2K | R25 | R0402 | 41.2K
40 | 1 | 6.65K | R26 | R0402 | 6.65K
41 | 1 | 422kΩ | R27 | R0603_NEW | 422kΩ | 0805W8F1003T5E | UNI-ROYAL(厚声) |  | LCSC
42 | 1 | 100kΩ | R28 | R0603_NEW | 100kΩ | 0805W8F1003T5E | UNI-ROYAL(厚声) | C149504 | LCSC
43 | 1 | 10R | R29 | R0402 | 10R
44 | 1 | 53.6kΩ | R30 | R0402 | 53.6kΩ | 0402WGF5362TCE | UNI-ROYAL(厚声) |  | LCSC
45 | 1 | 24.9K | R31 | R0402 | 24.9K
46 | 1 | 5mΩ | R32 | RES-SMD_L6.4-W3.2_LR2512D-3W-1MR | 5mΩ | PMR100HZPFU5L00 | ROHM(罗姆) | C308572 | LCSC
47 | 1 | 49.9Ω | R33 | R0402 | 49.9Ω | 0805W8F1003T5E | UNI-ROYAL(厚声) |  | LCSC
48 | 2 | 5.1kΩ | R47,R48 | R0603 | 5.1kΩ | TNPW06035K10BEEA | VISHAY(威世) | C2088892 | LCSC
49 | 1 | 100kΩ | R70 | R0603 | 100kΩ | RCA03100KJLF | HKR(香港电阻) | C22356636 | LCSC
50 | 1 | 1MΩ | R71 | R0603 | 1MΩ | 0603WAF1004T5E | UNI-ROYAL(厚声) | C22935 | LCSC
51 | 1 | 2kΩ | R72 | R0603 | 2kΩ | 0603WAF2001T5E | UNI-ROYAL(厚声) | C22975 | LCSC
52 | 2 | VPT85BB-01A | T3,T4 | XFMR-SMD_L7.5-W6.7-P2.54-LS7.7-BL |  | VPT85BB-01A | VPSC(源特科技) | C2875071 | LCSC
53 | 4 | M3螺丝 | U1,U23,U24,U25 | M3螺丝
54 | 4 | XT30PW(2+2)-M.G.B | U2,U3,U5,U6 | CONN-TH_4P-XT30PW-M |  | XT30PW(2+2)-M.G.B | AMASS(艾迈斯) | C19268030 | LCSC
55 | 4 | 供电焊盘 | U4,U7,U8,U9 | 3*3焊盘
56 | 1 | SMBJ60CA | U10 | SMB_L4.5-W3.6-LS5.2-BI |  | SMBJ60CA | R+O(宏嘉诚) | C19077593 | LCSC
57 | 4 | 4PIN烧录口 | U11,U13,U16,U17 | 4PIN烧录口
58 | 1 | LM5148RGYR | U12 | VQFN-24_L5.5-W3.5-P0.50-BL-EP-2 |  | LM5148RGYR | TI(德州仪器) | C7470701 | LCSC
59 | 2 | 供电焊盘 | U14,U15 | 4*4焊盘
60 | 3 | YDC-LCZJB1-076 | U18,U19,U20 | CONN-SMD_YDC-LCZJB1-076 |  | YDC-LCZJB1-076 | SZydcn | C46866812 | LCSC
61 | 4 | STM32G431C8T6 | U22,U29,U41,U49 | LQFP-48_L7.0-W7.0-P0.50-LS9.0-BL |  | STM32G431C8T6 | ST(意法半导体) | C730096 | LCSC
62 | 2 | VPS8505 | U26,U38 | SOT-23-6_L2.9-W1.6-P0.95-LS2.8-BR |  | VPS8505 | VPSC(源特科技) | C2986360 | LCSC
63 | 2 | TPS76350DBVR-TP | U27,U39 | SOT-23-5_L3.0-W1.6-P0.95-LS2.8-BR |  | TPS76350DBVR-TP | TECH PUBLIC(台舟) | C5380676 | LCSC
64 | 4 | ISO1050DWR | U28,U40,U48,U50 | SOIC-16_L10.3-W7.5-P1.27-LS10.3-BL |  | ISO1050DWR | TI(德州仪器) | C93718 | LCSC
65 | 1 | TLV75733PDBVR | U55 | SOT-23-5_L2.9-W1.6-P0.95-LS2.8-BL |  | TLV75733PDBVR | TI(德州仪器) | C485517 | LCSC
66 | 4 | DSK36 | U56,U57,U58,U59 | SOD-123FL_L2.8-W1.9-LS3.7-RD |  | DSK36 | R+O(宏嘉诚) | C22466353 | LCSC
67 | 1 | SL2.1A | U60 | SOP-16_L10.0-W3.9-P1.27-LS6.0-BL |  | SL2.1A | CoreChips(和芯润德) | C192893 | LCSC
68 | 1 | TYPE-C 6P | USB1 | TYPE-C-SMD_TYPE-C-6P |  | TYPE-C 6P | SHOU HAN(首韩) | C456012 | LCSC
69 | 1 | TYPEC-304-BCP16 | USB2 | USB-C-SMD_TYPEC-304-BCP16 |  | TYPEC-304-BCP16 | XUNPU(讯普) | C720629 | LCSC
70 | 1 | 12MHz | X2 | CRYSTAL-SMD_4P-L3.2-W2.5-BL | 12MHz | XL2EL89CSI-111YLC-12M | YXC(扬兴晶振) | C5280576 | LCSC

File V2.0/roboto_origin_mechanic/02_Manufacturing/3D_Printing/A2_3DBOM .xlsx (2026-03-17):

Ebom of ROBOTO Origin
Total Price: |  |  | Edit by： |  | 周錾 |  |  | Date： | 2026.2.24
Version： |  | v2.0.0 | Review by： |  | 孙浩楠 |  |  | Date： | 2026.2.24
Product Model: |  | ATOM 01 | Approval by： |  | 孙浩楠 |  |  | Date： | 2026.2.24
Number | Part Number | Part Name | Management class | Material | Quantity | Unit | Version | Description | Classification
ATOM 01 v1.0.1 本体骨架
1 | 3d打印件 | PCB_转接板orangepi | A | pla | 1 | pcs | A | 黑色 | 3d打印
2 |  | PCB_转接板地瓜 | A | pla | 1 | pcs | A | 黑色 | 3d打印
3 |  | 大腿后侧标定 | A | pla | 1 | pcs | A | 黑色 | 3d打印
4 |  | 脚部标定件 | A | pla | 1 | pcs | A | 黑色 | 3d打印

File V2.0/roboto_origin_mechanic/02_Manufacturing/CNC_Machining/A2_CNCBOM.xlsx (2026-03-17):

Ebom of ROBOTO Origin
Total Price: |  |  | Edit by： |  | 周錾 |  |  | Date： | 2026.3.04
Version： |  | v1.0.2 | Review by： |  | 孙浩楠 |  |  | Date： | 2026.3.04
Product Model: |  | roboto_origin | Approval by： |  | 孙浩楠 |  |  | Date： | 2026.3.04
Number | Part Number | Part Name | Management class | Material | Quantity | Unit | Version | Description | Classification
ATOM 01 v1.0.1 本体骨架
1 | RB000152_02 | 手臂1 | A | 6061铝合金 | 2 | pcs | A | 120目喷砂/黑色阳极氧化 | 金属加工类-CNC件
2 | RB000153_02 | 手臂2 | A | 6061铝合金 | 4 | pcs | A | 120目喷砂/黑色阳极氧化 | 金属加工类-CNC件
3 | RB000154_02 | 手臂3 | A | 6061铝合金 | 4 | pcs | A | 120目喷砂/黑色阳极氧化 | 金属加工类-CNC件
4 | RB000155_01 | 手臂4 | A | 6061铝合金 | 4 | pcs | A | 120目喷砂/黑色阳极氧化 | 金属加工类-CNC件
5 | RB000156_01 | IMU载板 | A | 6061铝合金 | 1 | pcs | A | 120目喷砂/黑色阳极氧化 | 金属加工类-CNC件
6 | RB000157_01 | 侧板横板 | A | 6061铝合金 | 2 | pcs | A | 120目喷砂/黑色阳极氧化 | 金属加工类-CNC件
7 | RB000158_02 | 大腿内侧 | A | 6061铝合金 | 2 | pcs | A | 120目喷砂/黑色阳极氧化 | 金属加工类-CNC件
8 | RB000159_02 | 电池底盖 | A | 7075铝合金 | 1 | pcs | A | 120目喷砂/黑色阳极氧化 | 金属加工类-CNC件
9 | RB000160_02 | 肩膀 | A | 6061铝合金 | 2 | pcs | A | 120目喷砂/黑色阳极氧化 | 金属加工类-CNC件
10 | RB000161_01 | 20cm脚 | A | 6061铝合金 | 2 | pcs | A | 120目喷砂/黑色阳极氧化 | 金属加工类-CNC件
11 | RB000162_01 | 脚底连杆 | A | 45钢 | 2 | pcs | A | 发黑 | 金属加工类-CNC件
12 | RB000163_01 | 脚踝横滚连接件 | A | 6061铝合金 | 4 | pcs | A | 120目喷砂/黑色阳极氧化 | 金属加工类-CNC件
13 | RB000164_01 | 髋关节固定 | A | 6061铝合金 | 1 | pcs | A | 120目喷砂/黑色阳极氧化 | 金属加工类-CNC件
14 | RB000166_02 | 输出法兰连杆 | A | 45钢 | 4 | pcs | A | 发黑 | 金属加工类-CNC件
15 | RB000167_03 | 通用连接件 | A | 6061铝合金 | 4 | pcs | A | 120目喷砂/黑色阳极氧化 | 金属加工类-CNC件
16 | RB000168_02 | 通用连接件扩孔法兰 | A | 6061铝合金 | 4 | pcs | A | 120目喷砂/黑色阳极氧化 | 金属加工类-CNC件
17 | RB000169_02 | 小腿 | A | 6061铝合金 | 2 | pcs | A | 120目喷砂/黑色阳极氧化 | 金属加工类-CNC件
18 | RB000170_02 | 胸腔夹板后 | A | 6061铝合金 | 1 | pcs | A | 120目喷砂/黑色阳极氧化 | 金属加工类-CNC件
19 | RB000171_01 | 胸腔前后夹板 | A | 6061铝合金 | 1 | pcs | A | 120目喷砂/黑色阳极氧化 | 金属加工类-CNC件
20 | RB000172_01 | 限位销 | A | 6061铝合金 | 4 | pcs | A | 120目喷砂/黑色阳极氧化 | 金属加工类-CNC件
21 | RB000173_01 | 小腿轴承锁 | A | 6061铝合金 | 4 | pcs | A | 120目喷砂/黑色阳极氧化 | 金属加工类-CNC件
22 | RB000174_03 | 腰部支撑 | A | 7075铝合金 | 1 | pcs | A | 120目喷砂/黑色阳极氧化 | 金属加工类-CNC件
23 | RB000175_02 | 长连杆 | A | 45钢 | 2 | pcs | A | 发黑 | 金属加工类-CNC件
24 | RB000176_02 | 短连杆 | A | 45钢 | 2 | pcs | A | 发黑 | 金属加工类-CNC件
25 | RB000177_02 | 髋夹板 | A | 6061铝合金 | 2 | pcs | A | 120目喷砂/黑色阳极氧化 | 金属加工类-CNC件
26 | RB000179_01 | 手臂5 | A | 6061铝合金 | 2 | pcs | A | 120目喷砂/黑色阳极氧化 | 金属加工类-CNC件

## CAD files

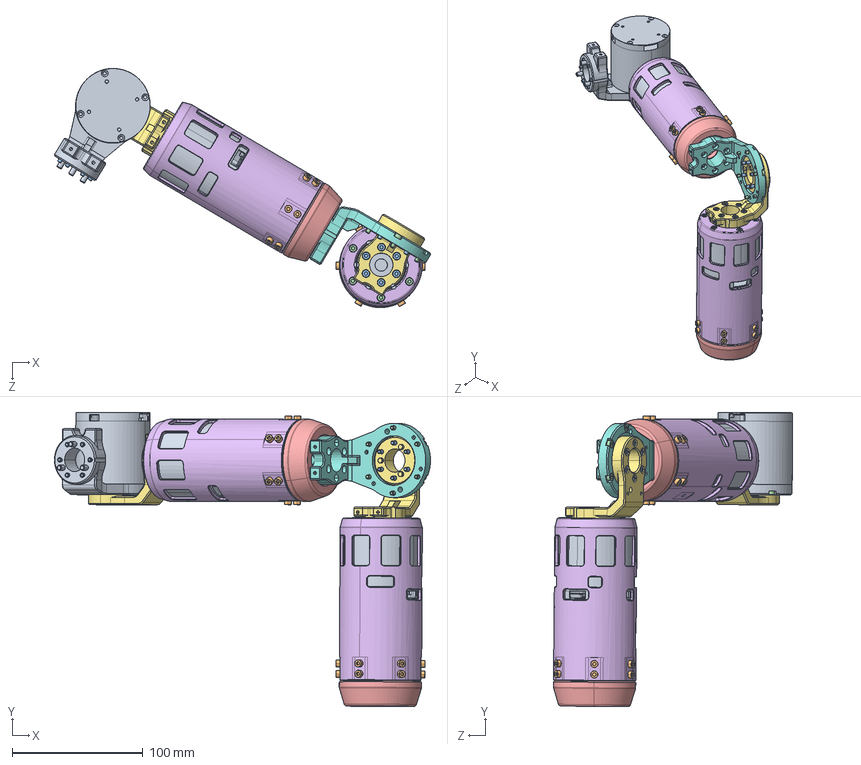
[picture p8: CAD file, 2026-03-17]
V2.0/roboto_origin_mechanic/01_SW_Project/roboto_origin_2.0/ATOM01手臂装配体（右）装配体.SLDASM
287.7 x 225.2 x 183.0 mm
DM 4340 rau 3505 电机 3D x 3
GB╱T 70.1-2008[内六角圆柱头螺钉M3×10] x 24
GB╱T 70.1-2008[内六角圆柱头螺钉M3×16] x 30
GB╱T 70.1-2008[内六角圆柱头螺钉M3×8] x 24
RB000155_01_手臂4 x 2
RB000154_02_手臂3 x 2
RB000153_02_手臂2 x 2
RB000152_02_手臂1
RB000179_01_手臂5

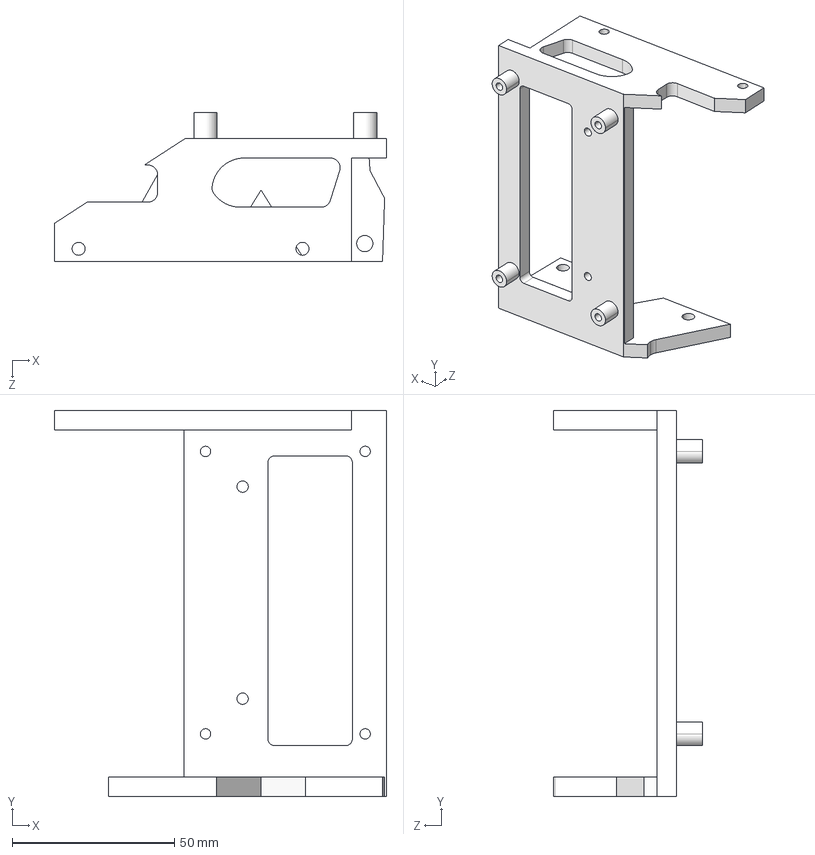
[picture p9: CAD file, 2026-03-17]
V2.0/roboto_origin_mechanic/02_Manufacturing/3D_Printing/A2_3D_print/PCB_转接板orangepi.STEP
102.4 x 119.0 x 45.9 mm

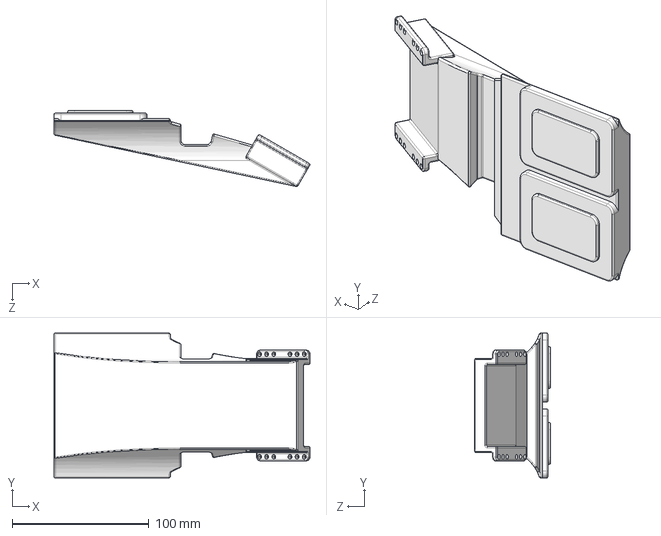
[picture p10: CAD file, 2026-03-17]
V2.0/roboto_origin_mechanic/02_Manufacturing/3D_Printing/总3d打印标定件/腰部标定件，数量1.STEP
187.2 x 106.0 x 55.7 mm

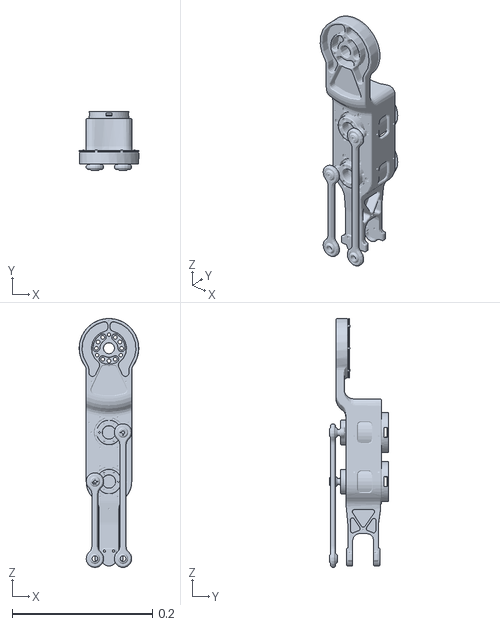
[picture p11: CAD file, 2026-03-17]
V2.0/roboto_origin_mechanic/03_URDF/meshes/right_knee_link.STL
0.085 x 0.0838 x 0.355

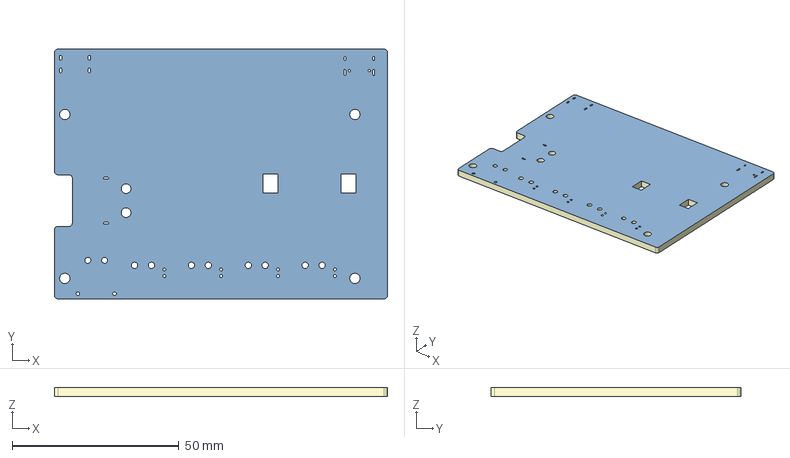
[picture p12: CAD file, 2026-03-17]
V2.0/roboto_origin_pcb/00_Docs/3D_PCB5_11_2026-2-1.step
100.0 x 75.0 x 2.63 mm
Board~LYl7
TopCopper~LYl7
BottomCopper~LYl7
TopFpcStiffener~LYl7
BottomFpcStiffener~LYl7

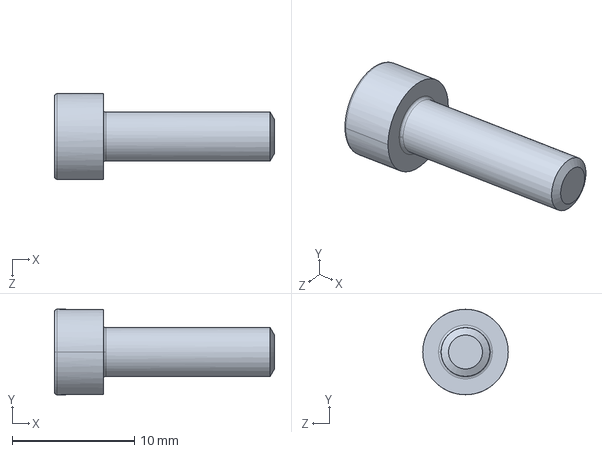
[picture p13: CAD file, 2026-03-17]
V2.0/roboto_origin_mechanic/01_SW_Project/roboto_origin_2.0/GB╱T 70.1-2008[内六角圆柱头螺钉M4×14].SLDPRT
18.0 x 7.00 x 7.00 mm

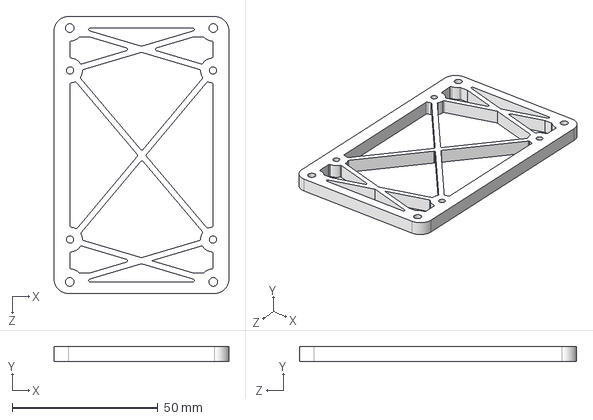
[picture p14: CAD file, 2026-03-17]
V2.0/roboto_origin_mechanic/02_Manufacturing/3D_Printing/A2_3D_print/PCB转接板地瓜.STEP
60.0 x 5.00 x 95.0 mm

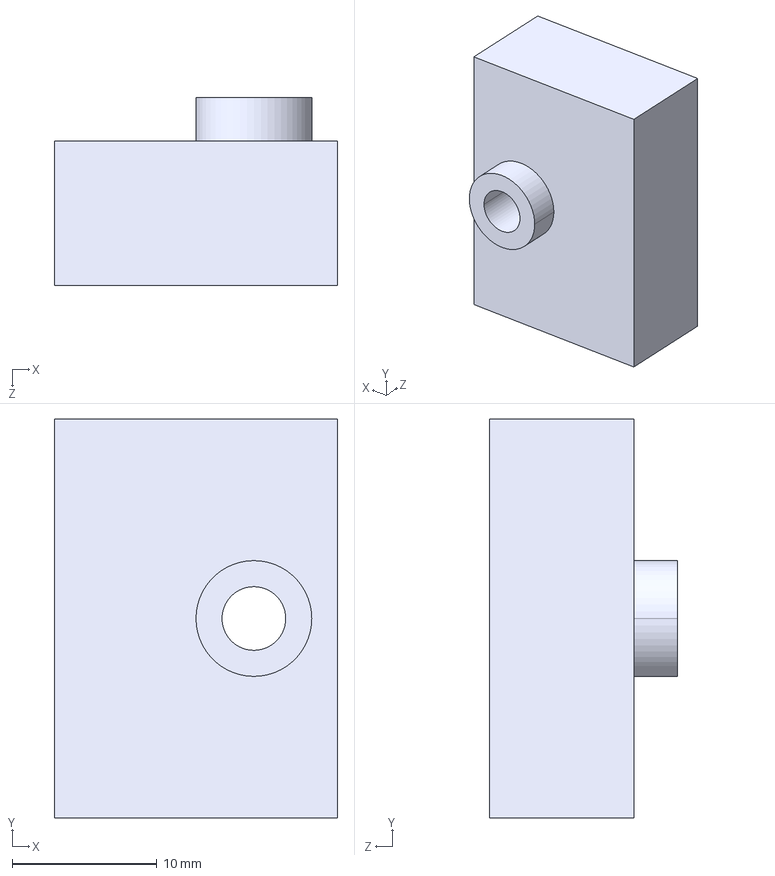
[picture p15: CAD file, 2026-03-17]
V2.0/roboto_origin_mechanic/02_Manufacturing/3D_Printing/总3d打印标定件/大腿定位块，数量2.STEP
19.6 x 27.6 x 13.0 mm

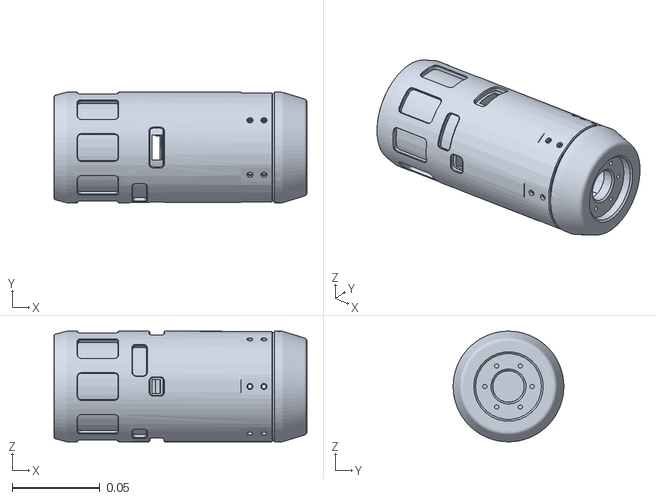
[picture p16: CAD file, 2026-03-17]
V2.0/roboto_origin_mechanic/03_URDF/meshes/right_elbow_yaw_link.STL
0.144 x 0.063 x 0.063

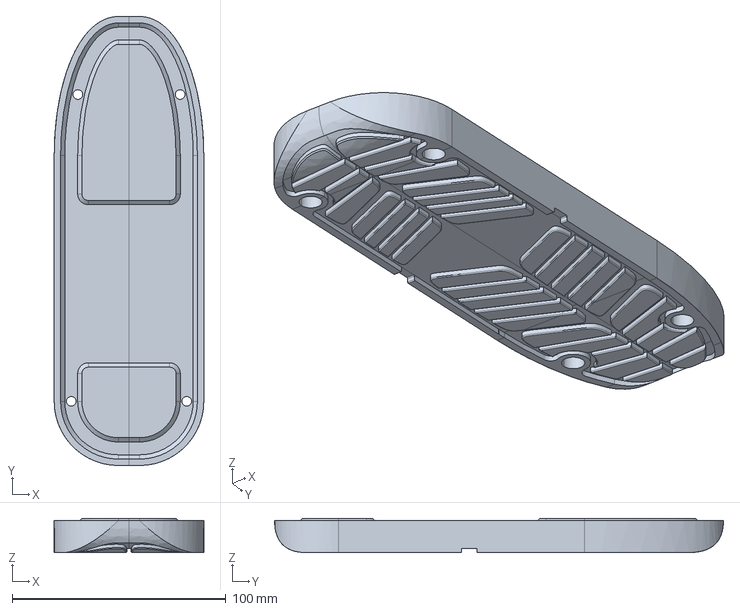
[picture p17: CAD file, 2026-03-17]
V2.0/roboto_origin_mechanic/01_SW_Project/roboto_origin_2.0/Roboto_Origin_ShoePad_01-0225.stp
70.0 x 210.0 x 16.0 mm

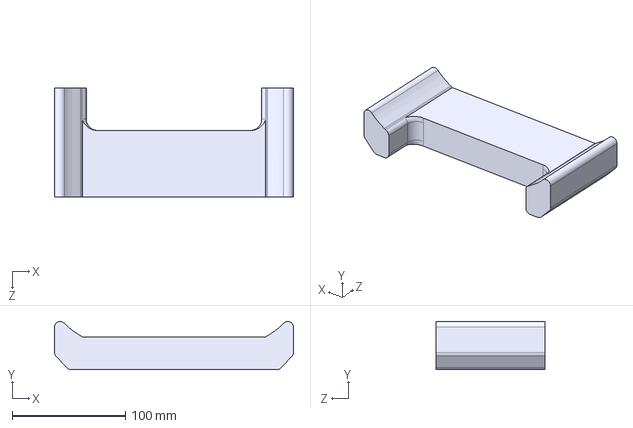
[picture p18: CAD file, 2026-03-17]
V2.0/roboto_origin_mechanic/02_Manufacturing/3D_Printing/A2_3D_print/大腿后侧标定，数量1.STEP
210.7 x 42.4 x 96.0 mm

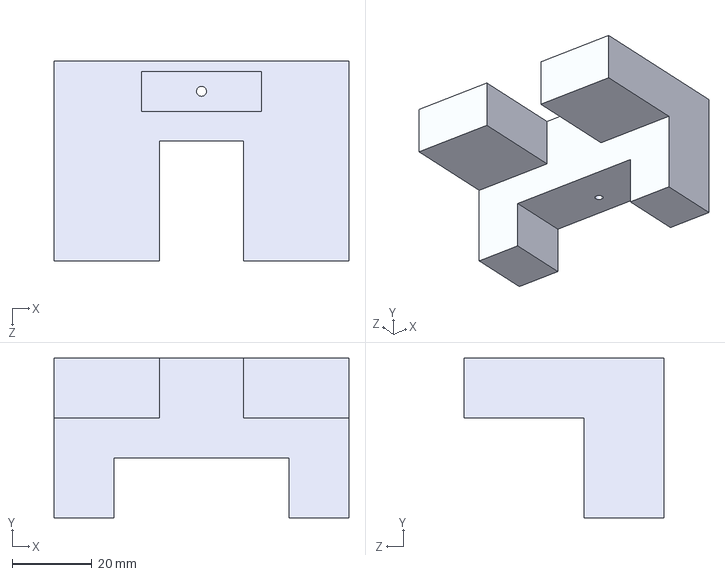
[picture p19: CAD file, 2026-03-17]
V2.0/roboto_origin_mechanic/02_Manufacturing/3D_Printing/总3d打印标定件/脚踝标定，数量2.STEP
73.9 x 40.0 x 50.0 mm

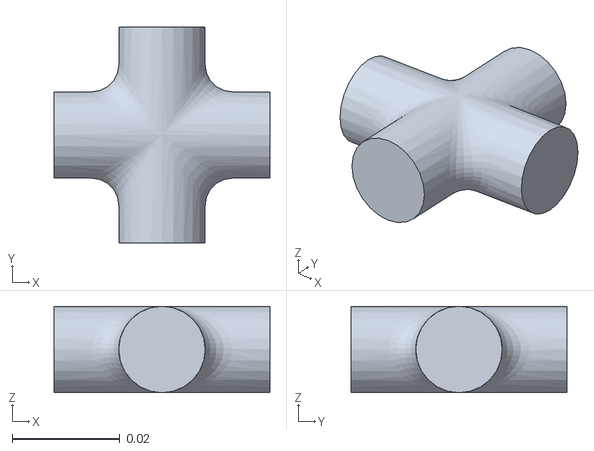
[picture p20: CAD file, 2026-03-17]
V2.0/roboto_origin_mechanic/03_URDF/meshes/right_ankle_pitch_link.STL
0.04 x 0.04 x 0.016

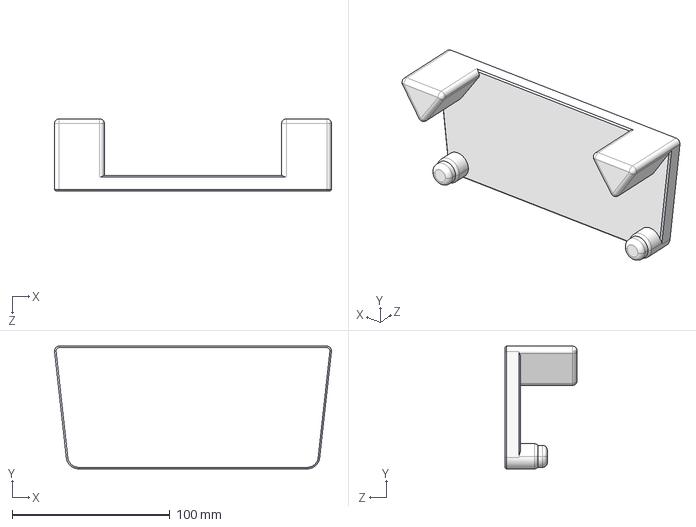
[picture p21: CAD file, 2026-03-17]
V2.0/roboto_origin_mechanic/02_Manufacturing/3D_Printing/A2_3D_print/脚部标定件，数量1.STEP
175.9 x 78.0 x 46.0 mm

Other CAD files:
V2.0/roboto_origin_mechanic/01_SW_Project/roboto_origin_2.0/定位尺寸.SLDASM
V2.0/roboto_origin_mechanic/01_SW_Project/roboto_origin_2.0/镜向ATOM01手臂装配体（右）装配体.SLDASM
V2.0/roboto_origin_mechanic/02_Manufacturing/3D_Printing/总3d打印标定件/肘部标定件，数量2.STEP
V2.0/roboto_origin_mechanic/03_URDF/meshes/left_arm_roll_link.STL
V1.0/atom01_mechanic/01_SW_Project/01总标定件/肘部标定件，数量2.STEP
V1.0/atom01_mechanic/01_SW_Project/01总标定件/肩部固定件，数量2.STEP
V1.0/atom01_mechanic/01_SW_Project/01总标定件/膝盖标定，数量2.STEP
V1.0/atom01_mechanic/01_SW_Project/16x40十字轴承.SLDPRT
V1.0/atom01_mechanic/01_SW_Project/20cm脚.STEP
V1.0/atom01_mechanic/01_SW_Project/20cm脚/20cm脚.SLDDRW
V1.0/atom01_mechanic/01_SW_Project/20cm脚/20cm脚.SLDPRT
V1.0/atom01_mechanic/01_SW_Project/20cm脚/20cm脚.STEP
V1.0/atom01_mechanic/01_SW_Project/270x60x70电池.SLDPRT
V1.0/atom01_mechanic/01_SW_Project/48转5v.SLDPRT
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

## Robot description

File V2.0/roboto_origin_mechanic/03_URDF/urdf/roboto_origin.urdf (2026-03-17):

<?xml version="1.0" encoding="utf-8"?>
<robot name="atom01urdf">
  <link name="base_link">
   <inertial>
<origin xyz="-0.04700769 -0.00000239 -0.00862801" rpy="0 0 0" />
  
  <mass value="5.51295532" />
  
  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
</inertial>
    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
  </link>
  <link name="left_thigh_yaw_link">
  <inertial>
<origin xyz="-0.03847656 -0.0000142 -0.05612329" rpy="0 0 0" />
  
  <mass value="1.71784575" />
  
  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
</inertial>
    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
  </link>
  <joint name="left_thigh_yaw_joint" type="revolute">
    <origin xyz="-0.071093 0.0725 -0.051778" rpy="0 0 0" />
    <parent link="base_link" />
    <child link="left_thigh_yaw_link" />
    <axis xyz="-0.5 0 -0.86603" />    
    <limit lower="-1" upper="0.2" effort="80" velocity="10.47" />
  </joint>
  <link name="left_thigh_roll_link">
   <inertial>
 <origin xyz="0.05748778 -0.00601901 -0.03308921" rpy="0 0 0" />
  
  <mass value="1.66236465" />
  
  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
</inertial>
    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
  </link>
  <joint name="left_thigh_roll_joint" type="revolute">
    <origin xyz="-0.017693 0 -0.072346" rpy="0 0 0" />
    <parent link="left_thigh_yaw_link" />
    <child link="left_thigh_roll_link" />
    <axis xyz="0.86603 0 -0.5" />
    <limit lower="-0.2" upper="1" effort="80" velocity="10.47" />
  </joint>
  <link name="left_thigh_pitch_link">
<inertial>
  <origin xyz="0.00004587 -0.01904764 -0.19858149" rpy="0 0 0" />
  
  <mass value="2.34600715" />
  
  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
</inertial>
    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
  </link>
  <joint name="left_thigh_pitch_joint" type="revolute">
    <origin xyz="0.060622 0.02085 -0.035" rpy="0 0 0" />
    <parent link="left_thigh_roll_link" />
    <child link="left_thigh_pitch_link" />
    <axis xyz="0 1 0" />
    <limit lower="-1.57" upper="1.57" effort="80" velocity="10.47" />
  </joint>
  <link name="left_knee_link">
   <inertial>
 <origin xyz="-0.00035292 -0.0132798 -0.15208271" rpy="0 0 0" />
  <mass value="1.70223945" />
  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
</inertial>
    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
  </link>
  <joint name="left_knee_joint" type="revolute">
    <origin xyz="0 0 -0.25" rpy="0 0 0" />
    <parent link="left_thigh_pitch_link" />
    <child link="left_knee_link" />
    <axis xyz="0 1 0" />
    <limit lower="-0.2" upper="2.5" effort="80" velocity="10.47" />
  </joint>
  <link name="left_ankle_pitch_link">
<inertial>
  <origin xyz="0.0 0.0 0.0" rpy="0 0 0" />
  
  <mass value="0.084" />
  
  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
</inertial>
    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
  </link>
  <joint name="left_ankle_pitch_joint" type="revolute">
    <origin xyz="0 -0.02085 -0.3" rpy="0 0 0" />
    <parent link="left_knee_link" />
    <child link="left_ankle_pitch_link" />
    <axis xyz="0 1 0" />
    <limit lower="-0.6" upper="0.6" effort="18" velocity="3.7692" />
  </joint>
  <link name="left_ankle_roll_link">
<inertial>
  <origin xyz="0.01454282 0.00284825 -0.02908608" rpy="0 0 0" />
  
  <mass value="0.33517651" />
  
  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
</inertial>
    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
  </link>
  <joint name="left_ankle_roll_joint" type="revolute">
    <origin xyz="0 0 0" rpy="0 0 0" />
    <parent link="left_ankle_pitch_link" />
    <child link="left_ankle_roll_link" />
    <axis xyz="1 0 0" />
    <limit lower="-0.5" upper="0.5" effort="18" velocity="3.7692" />
  </joint>
  <link name="right_thigh_yaw_link">
   <inertial>
<origin xyz="-0.03847656 0.0000142 -0.05612329" rpy="0 0 0" />
  
  <mass value="1.71632614" />
  
  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
</inertial>
    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
  </link>
  <joint name="right_thigh_yaw_joint" type="revolute">
    <origin xyz="-0.071093 -0.0725 -0.051778" rpy="0 0 0" />
    <parent link="base_link" />
    <child link="right_thigh_yaw_link" />
    <axis xyz="-0.5 0 -0.86603" />
    <limit lower="-0.2" upper="1" effort="80" velocity="10.47" />
  </joint>
  <link name="right_thigh_roll_link">
   <inertial>
<origin xyz="0.05748778 0.00601901 -0.03308921" rpy="0 0 0" />
  
  <mass value="1.66310652" />
  
  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
</inertial>
    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
  </link>
  <joint name="right_thigh_roll_joint" type="revolute">
    <origin xyz="-0.0189924084475403 0 -0.0715958163677252" rpy="0 0 0" />
    <parent link="right_thigh_yaw_link" />
    <child link="right_thigh_roll_link" />
    <axis xyz="0.86603 0 -0.5" />
    <limit lower="-1" upper="0.2" effort="80" velocity="10.47" />
  </joint>
  <link name="right_thigh_pitch_link">
  <inertial>
  <origin xyz="0.00004587 0.01904764 -0.19858149" rpy="0 0 0" />
  
  <mass value="2.34600715" />
  
  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
</inertial>
    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
  </link>
  <joint name="right_thigh_pitch_joint" type="revolute">
    <origin xyz="0.0619208163652291 -0.0208499999999942 -0.0357500000093095" rpy="0 0 0" />
    <parent link="right_thigh_roll_link" />
    <child link="right_thigh_pitch_link" />
    <axis xyz="0 1 0" />
    <limit lower="-1.57" upper="1.57" effort="80" velocity="10.47" />
  </joint>
  <link name="right_knee_link">
<inertial>
 <origin xyz="-0.00035292 0.0132798 -0.15208271" rpy="0 0 0" />
  
  <mass value="1.70223945" />
  
  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
</inertial>
    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
  </link>
  <joint name="right_knee_joint" type="revolute">
    <origin xyz="0 0 -0.250000000000016" rpy="0 0 0" />
    <parent link="right_thigh_pitch_link" />
    <child link="right_knee_link" />
    <axis xyz="0 1 0" />
    <limit lower="-0.2" upper="2.5" effort="80" velocity="10.47" />
  </joint>
  <link name="right_ankle_pitch_link">
    <inertial>
  <origin xyz="0.0 0.0 0.0" rpy="0 0 0" />
  
  <mass value="0.084" />
  
  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
</inertial>
    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
  </link>
  <joint name="right_ankle_pitch_joint" type="revolute">
    <origin xyz="0 0.0208500000000073 -0.299999999999986" rpy="0 0 0" />
    <parent link="right_knee_link" />
    <child link="right_ankle_pitch_link" />
    <axis xyz="0 1 0" />
    <limit lower="-0.6" upper="0.6" effort="18" velocity="3.7692" />
  </joint>
  <link name="right_ankle_roll_link">
    <inertial>
<origin xyz="0.01454282 -0.00284825 -0.02908608" rpy="0 0 0" />
  
  <mass value="0.33517651" />
  
  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
</inertial>
    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
  </link>
  <joint name="right_ankle_roll_joint" type="revolute">
    <origin xyz="0 0 0" rpy="0 0 0" />
    <parent link="right_ankle_pitch_link" />
    <child link="right_ankle_roll_link" />
    <axis xyz="1 0 0" />
    <limit lower="-0.5" upper="0.5" effort="18" velocity="3.7692" />
  </joint>
  <link name="torso_link">
   <inertial>
 <origin xyz="-0.00234775 -0.00000466 0.0984446" rpy="0 0 0" />
  <mass value="7.58189737" />
  
  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
</inertial>
    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
  </link>
  <joint name="torso_joint" type="revolute">
    <origin xyz="-0.0281649492242451 0 0.0672000000054882" rpy="0 0 0" />
    <parent link="base_link" />
    <child link="torso_link" />
    <axis xyz="0 0 1" />
    <limit lower="-3.14" upper="3.14" effort="80" velocity="10.47" />
  </joint>
  <link name="left_arm_pitch_link">
   <inertial>
 <origin xyz="-0.00436523 0.04995146 0.0" rpy="0 0 0" />
  
  <mass value="0.47284363" />
  
  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
</inertial>
    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
  </link>
  <joint name="left_arm_pitch_joint" type="revolute">
    <origin xyz="0 0.121749999999383 0.206175860782433" rpy="0 0 0" />
    <parent link="torso_link" />
    <child link="left_arm_pitch_link" />
    <axis xyz="0 1 0" />
    <limit lower="-1.57" upper="1.57" effort="18" velocity="3.7692" />
  </joint>
  <link name="left_arm_roll_link">
   <inertial>
 <origin xyz="-0.0029007 0.0 -0.02197112" rpy="0 0 0" />
  
  <mass value="0.08401883" />
  
  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
</inertial>
    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
  </link>
  <joint name="left_arm_roll_joint" type="revolute">
    <origin xyz="0.0200000000000018 0.056 0" rpy="0 0 0" />
    <parent link="left_arm_pitch_link" />
    <child link="left_arm_roll_link" />
    <axis xyz="1 0 0" />
    <limit lower="-0.25" upper="1" effort="18" velocity="3.7692" />
  </joint>
  <link name="left_arm_yaw_link">
   <inertial>
<origin xyz="-0.00004328 -0.0018211 -0.10615895" rpy="0 0 0" />
  
  <mass value="1.15324354" />
  
  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
</inertial>
    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
  </link>
  <joint name="left_arm_yaw_joint" type="revolute">
    <origin xyz="-0.0200000000000002 0 -0.049999999999998" rpy="0 0 0" />
    <parent link="left_arm_roll_link" />
    <child link="left_arm_yaw_link" />
    <axis xyz="0 0 -1" />
    <limit lower="-1.57" upper="1.57" effort="18" velocity="3.7692" />
  </joint>
  <link name="left_elbow_pitch_link">
   <inertial>
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

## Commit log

2026-03-17 V2.0更新
    [16x40十字轴承.SLDPRT, 20cm脚.SLDDRW, 20cm脚.SLDPRT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]
2026-03-17 修改V1.0readme
